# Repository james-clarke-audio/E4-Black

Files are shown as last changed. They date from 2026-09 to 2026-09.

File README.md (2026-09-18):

# E4 — "E4-Black"

An **STM32F411 micromouse**: a C++ port of the ukmars
[**mazerunner-core**](https://github.com/ukmars/mazerunner-core) firmware onto
custom hardware, with a **Web Bluetooth** companion app for live telemetry,
control and calibration. Built for the October 2026 micromouse competition.

> **Status:** active development — hardware bring-up and sensor calibration.

## Features

- **1 kHz control loop** (SysTick) — motion, sensing and the search brain all
  run deterministically.
- **IR wall sensing** — four emitter/detector pairs, ambient-subtracted with a
  batched dark-then-lit read. Two forward sensors (front wall) and two diagonal
  sensors (side walls / centring).
- **Gyro heading** — the gyro holds heading; the side sensors handle lateral
  position and wall presence. Gyro scale is **calibrated on the floor and
  persisted to EEPROM**, not compiled in — it is a property of the individual
  MPU-9250 and shifts with temperature, so it can be re-measured at a venue
  with nothing but the companion app.
- **On-board UI** — SSD1306 OLED with a two-button menu; the whole menu is also
  drivable over Bluetooth.
- **Bluetooth telemetry & control** via the companion app — a Control tab for
  watching and driving her, and a Tuning tab for setting her up: live IR
  monitor, an emitter-hold camera aid for aiming, live turn tuning (gyro-closed
  spins & arcs), and firmware-version reporting.
- **Non-blocking wall sampling** (opt-in) — a five-state sampler ticked from the
  control ISR returns a full ambient-subtracted set every 5 ms with no
  busy-wait, so the wall flags stay live while she's moving.
- **Maze persistence** to on-board EEPROM.
- **Flood-fill search / speed run** from mazerunner-core, with a virtual/real
  sensor switch so the brain can be exercised in simulation.
- **A route executor** — one walk that either drives a planned route or
  rehearses it, so the rehearsal proves the sequencing the driver uses.
- **Time-weighted route planner** — least time rather than fewest cells, with
  diagonals *searched* rather than substituted, and an optimistic twin of each
  plan that says how much is still left to find.
- **Wall follower**, both hands, driven and simulated — its own competition
  class rather than a fallback solver.
- **A simulator that runs at the speed the motion model predicts**, so a
  simulated run takes as long as it claims to and the two numbers can be
  compared. Playback can be sped up for watching; the reported figure never
  moves with it.
- **A maze editor in the companion app** — draw a course on the big canvas,
  save it as text or `.maz`, and send it straight to her. Quicker than hunting
  through 406 files for one that exercises the thing you are testing.

## Hardware

- **MCU:** STM32F411CEU6 (Cortex-M4F, "Black Pill"-class).
- **Wall sensors:** 4× IR pairs — TSAL6100 emitters (940 nm) into OP505A
  phototransistors; emitters switched low-side by FDV301N MOSFETs from a 5 V
  rail. (The original board carried SFH4550; the sensor assemblies now fitted
  are TSAL6100.)
- **Display / storage:** SSD1306 OLED and a 24LC256 EEPROM, both on I2C1.
- **Drive:** DRV8833 motor driver, plus a gyro for heading.

Full pin map, sensor geometry and housing detail are in the reference manual
(see below).

## Build & run

- **Firmware:** STM32CubeIDE (2.2 / GCC 14). Import `Source/` as an existing
  project, build the **Debug** config, and flash over ST-Link to the
  STM32F411CEU6.
- **Companion app:** open `e4-maze.html` in a Web Bluetooth browser — Chrome or
  Edge on desktop, or an iPad via a WebBLE browser such as Bluefy (iOS Safari
  has no Web Bluetooth). Pair over BLE to monitor the sensors, drive the menu,
  and read the running firmware version.
- **Hosted copy:** the repo publishes to GitHub Pages, so the current app is
  always live at
  [`/E4-Black/e4-maze.html`](https://james-clarke-audio.github.io/E4-Black/e4-maze.html)
  and the manual at [`/E4-Black/docs/`](https://james-clarke-audio.github.io/E4-Black/docs/).
  Web Bluetooth needs a secure context, so on a tablet this is the route to use
  rather than copying the file across.

## Documentation

The **E4 Reference Manual** lives in [`docs/`](docs/index.html) — open
`docs/index.html`. Eleven chapters: overview, architecture & pin map, sensor
aim, sensor geometry, sensor housing, the firmware/menu map, position integrity
("Staying Located"), a design note for the next board (STM32G474), how she
chooses her path, the turn table, and the sensor carrier.

## Repository layout

| Path | What it is |
|---|---|
| `Source/` | STM32CubeIDE firmware project (Core / Drivers / Modules / Program). |
| `CompanionApp/` | Native SwiftUI companion (macOS/iPad) + the `E4Core` package — **the tool she is driven from**. |
| `e4-maze.html` | Web Bluetooth companion app (single file); follows the Swift app rather than leading it. |
| `docs/` | The reference manual (`index.html` + chapters). |
| `3D Files/` | Sensor housings, wheels, mounts, and the sensor socket plate (STL, print notes, and the parametric source that generates and verifies it). |
| `tools/planner-bench/` | Native build of the route planner, for scoring routes against the maze files without a robot. |
| `tools/bench-mazes/` | Finds and writes the per-turn tuning rigs, and checks the shipped files by planning them. |
| `mazefiles/` | 408 real competition mazes, binary and text, plus `bench/` — twelve single-corridor tuning rigs. |
| `E4-cell-alignment-A4.pdf` | 1:1 print jig for squaring a test cell. |

See [CONTRIBUTING.md](CONTRIBUTING.md) for the fuller layout and workflow.

## Contributing

`main` is protected: collaborators work on a branch and open a pull request.
Details, commit style and the firmware-version convention are in
[CONTRIBUTING.md](CONTRIBUTING.md).

## Credits

Firmware is a port of Peter Harrison's ukmars **mazerunner-core**. Thanks to the
UK micromouse community.

## License

Released under the [MIT License](LICENSE) — © 2022 Peter Harrison
(ukmars mazerunner-core), © 2026 James Clarke. E4 is a derivative of the
MIT-licensed mazerunner-core and keeps the same terms.

---

## Firmware releases

`FW_VERSION` lives in `Source/Program/inc/version.h`, shows on the OLED splash
and is reported over Bluetooth (`VER?`). **Minor** for a feature, **patch** for
a fix. **1.0.0 is reserved** for the build that goes to the October competition
— everything before it is bring-up.

Each entry names the firmware commit; companion-app and docs commits that
landed alongside are listed after it, since the two move together. Newest
first.

**0.34 — 18 Sep 2026 · The post loop**
From an old lab note of James's: drive into a cell, then round a post
continuously, watch the centre drift and adjust α. It is a better rig than the
zigzag, and one line of geometry says why.

**Four chained same-hand 90s of radius 90 *are* a circle centred on a post.**
She comes up the lane at x = 90 turning right; the arc centre sits 90 mm to her
right, which is the post. After the quarter she is heading east and her right is
now south — the same point. Every quarter shares a centre, so the four are one
circle, 565.5 mm round.

Which pins ω: `R = v/ω`, so R = 90 at 300 mm/s needs **191 °/s** — the figure
`SS180` already holds, because its lateral step of 2R is also one cell. And it
reconciles the two numbers in Ch 10: **226 is the figure for a turn driven on
its own**, where ω ramps to zero at the end and the trapezoid swings wider than
the ideal circle. Driven continuously there are no ramps between the quarters,
so the ideal `R = v/ω` applies and 191 is simply right. Two manoeuvres, two
answers, and the loop is the one that matches what a chained turn has to be.

**It separates ω from α.** Over a closed lap the four local frames sit at 0°,
90°, 180° and 270°, so any consistent per-turn displacement error sums to zero —
radius, offsets, tangential lag alike. Heading does not: the frames precess, the
lap stops closing, and the centre walks by about `2.83·|d|·ε`.

| error per turn | drift per lap | after 8 laps |
|---|---|---|
| 0.1° | 0.6 mm | 5 mm |
| 1.0° | 6.3 mm | 50 mm |

So ω sets the *size* of the circle and α sets the *drift* of its centre. It is
also the honest gyro-scale test — at running speed with the wheels rolling
rather than scrubbing in place — and the two causes separate, since scale error
is speed-independent while α's grows with ω. Odometry gives the radius back for
nothing: arc distance over 2π·laps, reported as `R_meas` beside the 90 it wants.

`Post loop` (Calibration, or BT `A`), set up by `LOOP,laps,ω,α,hand,speed`. It
is its own menu action rather than another use of `ARC` because **1440° is not a
turn** and writing it into a row would ruin the row.

*Alongside:* page 15 of `E4-bench-diagnostics-A4.pdf` draws the rig — a 2×2
block with the middle post free-standing, the 90 mm circle to mark round it, the
tangent run-in, and what a degree per turn looks like after one, four and eight
laps. Her outline on every page is now the real one: the chassis board is 77
wide with wheel wells stepping in to 11.46/65.54, 100 long with a semicircular
nose of radius 38, and the axle 35 mm from the back — all of it already written
down in Ch 11, Ch 4 and `config.c`.

**0.33 — 18 Sep 2026 · The approach is part of the turn**
A tuning run is *drive to the turn, make it, drive out* — and the first of those
three was the one the tuner could not be asked for. `ARC`'s fifth field writes
`entry_offset`, and `run_arc_from_table()` passed `entry_offset` straight in as
the lead-in, so the arc always began that many millimetres after she started
moving. Fine for "does this arc look right"; useless for "does she come out of
it in the lane", which is the only question a bench answers.

The approach is now counted in cells and the millimetres derived:

| entered from | lead-in |
|---|---|
| a straight | `BACK_WALL_TO_CENTER + cells × FULL_CELL − entry_offset` |
| the diagonal | `cells × DIAG_PITCH − entry_offset` |

`DS45`, `DS135` and `DD90` begin **on** the diagonal, where the pitch is 127.279
and there is no back wall to square up on — she is placed on the line by hand.
Which case applies follows from the row rather than from a switch someone has to
remember: a turn that leaves the diagonal is a turn that was already on it.
`POS,<cells>` sets it, `TUNE,pos=,lead=,pitch=` reports what she will actually
drive *before* anything moves, and `TURNRES` carries the row and the lead so a
log line three runs back still means something.

**The card does the arithmetic before she does.** `R = v / ω`, and an arc joining
two lanes that cross at θ is tangent to both only at `R·tan(θ/2)` either side of
the crossing. There is one wrinkle, and it took drawing the maze out 1:1 to see
it: `entry_offset` is measured back from the **lattice point** the planner books
the turn at, which for most turns is also where the two lanes cross — but an
`SD45` is booked in at a **cell centre**, while a straight lane meets a diagonal
at the **wall midpoint 90 mm earlier**. That half cell is part of the offset.

| row | ω | R at 300 | tangent | + half cell | needs | has | |
|---|---|---|---|---|---|---|---|
| SS90E | 170 | 101 | 101 | — | 101 | 100 | agrees |
| DD90 | 273 | 63 | 63 | — | 63 | 63 | agrees |
| **DS45** | **95** | **181** | **75** | **—** | **75** | **120** | **does not** |
| **SD45** | **95** | **181** | **75** | **90** | **165** | **120** | **does not** |

So the two 45 rows cannot both be right while they share a number — one needs
165 and the other 75. The same 120 sits in the planner as `sd45_offset` /
`ds45_offset`, so those move with them. The Tuning screen shows the gap and
offers the figure; the floor decides which of the numbers was wrong, but it
cannot until they agree.

One number says it best: a diagonal step is 127.3 mm and `ds45_offset` is 120 of
it, so on `bench-3x3-45min` the DS45 gets **seven millimetres** of approach
before the arc starts. At the tangent value it gets 52. That is why the planner
abandons that geometry and drives `ARC_R, SPIN_L` instead.

*Alongside:* `E4-bench-diagnostics-A4.pdf` — the 1:1 cell template (centrelines,
corner-to-corner, and the diamond joining the four wall midpoints that is the
actual diagonal lane), plus a page per hand showing where the mouse gets put
down. `06fc12d` and `fa6d585` — `mazefiles/bench/`, twelve single-corridor
tuning rigs, and `tools/bench-mazes/` which found them by enumerating every
corridor that fits in a section and asking the real planner what each one
produces. Two results fell out of that search. A 3×3 entered at (0,0) facing
north can only turn right first, because the west perimeter is beside her —
`SD45_L` is unreachable there without a spin. And **(2,0) facing north is the
mirror image of (0,0) facing north**, so once the start pose is allowed to move,
every left-hand rig is the x-mirror of its right-hand twin, walk for walk.

**0.32 — 18 Sep 2026 · She can finish by turning into the goal**
Every goal test in `plan_native()` sat inside the cell-expansion loop, which
advances a cell *before* it looks. So a route that **arrives** at the goal by
turning into it was never recognised as finished: she drove past and came back,
or took a longer way round that happened to approach along a straight.

The node's own cell is now tested before the loop, with `best_cells = 0` and
`best_t = 0` because the turn that brought her there is already paid for in
`key`. `step_time()` returns `0.0f` for a zero-cell goal step rather than asking
`straight_time()` for a negative distance — the clock stops on *entering* the
goal, and what is left of that cell afterwards is not on it.

On Boston the last vertices went from `DS45_L (17,18) → (17,17) → GOAL (17,15)`
to `… → GOAL (17,17)`. Swept over the whole 394-maze corpus: **72 faster, 320
unchanged, 2 slower, 0 invalid**, mean 32.864 → 32.761 s. Best: japan1997f
−3.460 s, uk1992q −2.698 s, boston −1.544 s.

The two slower ones are not a regression in the fix. `key_of()` quantises time
to centiseconds — that is what makes Dial's bucket queue O(E) — so routes tying
on the quantised key can differ by up to ~10 ms a step, and ≤0.13 s over twenty
steps is inside one bucket width. Recorded here so nobody hunts it later.

**0.31 — 18 Sep 2026 · No toy maze at boot, and the editor can undo**
The boot scaffold seeded a two-cell maze with the goal at (1,1). It made a whole
class of mistake invisible: a Plan route run with **no maze sent** looked
entirely successful, because there really was a maze and she really did solve
it. She now boots with `maze.h`'s own `m_goal{7, 7}` and an open arena as ground
truth, so a run with nothing sent looks like what it is.

The companion app's maze editor grows undo — `history: [E4MazeFile]` with
`canUndo` / `undo()`, and ⌘Z on the canvas.

**0.30 — 17 Sep 2026 · She speeds up through ground she has already covered**
Watching a simulated explore, she never went any faster in cells she had already
been through — and she didn't, in either the simulator or the firmware.
`sim_move_seconds()` used `FULL_CELL / SEARCH_SPEED` for every cell, and
`search_to()` crawls at `SEARCH_SPEED` from the first cell to the last. The
simulator was faithfully showing what the firmware does, which is the simulator
doing its job.

**The test is per cell, not per leg.** The obvious version of this is to run the
whole return leg fast, on the grounds that she has just driven it. That is
wrong: the flood picks the best *known* path home and known does not mean
*visited* — she will have seen a cell's walls from next door without ever
entering it, and those cells are exactly where there is still something to
learn. So the return leg becomes an exploring run that happens to be quick in
the parts already covered.

`cruise_speed()` is that rule, in one place, used by the driven search and the
simulated one so neither models something the other does not do:

| condition | speed |
|---|---|
| the cell she is **entering** is fully visited, **and** the move out of it is straight | `RUN_SPEED` |
| anything else | `SEARCH_SPEED` |

The second condition is the one that is easy to forget. There is no room to shed
speed between a cell's sensing point and the turn point after it, so carrying run
speed into a turn means entering it too fast. Checking costs nothing: in visited
territory the map is complete, so `heading_to_smallest()` on the flood she
already has is a reliable one-cell look ahead.

**And a sloppy read at speed cannot hurt her**, which is what makes this safe
rather than merely fast. She still senses and still calls `update_map()` in a
cell crossed at 600 mm/s — but `update_wall_state()` refuses to change a wall
that has already been seen, and *fully visited* means every wall in that cell
has been. A bad reading is discarded by construction, in exactly the cells where
the rule allows speed. The only place a wrong wall could be written is a cell
with something unknown in it, and those are the cells she is required to crawl
through.

`sim_move_seconds()` now tracks the speed she is **carrying** and costs each move
with `timing::straight_time` — the planner's own model — so a run of visited
cells visibly winds up and the cell before a turn visibly sheds it, instead of
every cell costing a flat 0.6 s.

The wall follower stays at search speed throughout, deliberately: `cruise_speed()`
reads the flood to look ahead, and a follower never floods.

**0.29 — 17 Sep 2026 · The executor left a diagonal by the wrong side**
A diagonal speed run finished at **(1,0)** — near the start, nowhere near the
goal — having walked a staircase west and south with no 45° heading in it, on a
route whose time came back exactly right at 23199 ms.

One line. `run_route` left a diagonal with `nh = (L) ? ((dd + 3) & 3) : ((dd + 1) & 3)`.
"+3 to turn left" is correct *inside* an enum. This crosses from `Diag` to
`Head`, and those are different enums offset by half a turn: leaving a diagonal
to the left is **+0** and to the right is +1. The right hand was accidentally
correct, which is why it took a real route to expose.

What it does is worse than a wrong heading: it lands her on a **post**, the one
lattice point that is never occupied, so her half-cell coordinates lose their
parity and every orthogonal move afterwards keeps her on the wrong parity for
the rest of the route. Hence a whole run animated on the lines *between* cells —
which is exactly what the `POS` trail showed, every coordinate an even multiple
of 90.

Fixed in **one place, not two**: `diag_ccw`/`diag_cw` move from statics in
`native.cpp` to inline functions in `native.h`, so the executor uses the same
mapping `route_points()` does rather than a second copy of it. Two copies of that
mapping is how one of them went wrong.

And the walk checks itself now. A route ends at a cell **centre**, odd in both
half-cell coordinates; anything else means the walk lost the lattice and every
cell it has reported since is fiction. It says so — `SR,LOST u= v= diag=` —
rather than reporting a plausible wrong answer.

Verified on the maze that broke it: every vertex of the run now matches the
planned route exactly, and she finishes at (8,8).

**0.28 — 17 Sep 2026 · The route executor**
The planner has been able to answer since 0.20 and nothing acted on the answer.
`run_route()` does.

**One walk serves both the real run and the rehearsal.** The part worth getting
right is the sequencing — which turn, after how many cells, from which heading —
and a simulator that sequenced differently from the driver would prove nothing
about the driver. The only thing the `simulate` flag changes is whether a step
is animated or driven.

Timing comes from a new `route_times()` in `diagonal.cpp`, which walks the route
with the **same `step_time()` that costed it** and reports each step split into
the run before the turn and the turn itself. That split is what lets the
rehearsal animate a step at its true duration, and it means the simulated total
equals `route.seconds` by construction rather than by coincidence.

    Sim speed run   F    plan, then rehearse at the speed the model predicts
    Speed run       l    plan, then drive
    KIND,<0|1|2>         shortest · quickest · quickest with diagonals

Which route is a **setting** rather than three menu entries, because the three
are one run with a different cost function and the point is comparing them back
to back on one maze. The default is quickest orthogonal: the diagonal route is
faster on paper, but every diagonal row of the turn table is arithmetic that has
never met a floor.

Both actions **stream the route before executing it**, so the line she is about
to take is on screen before she takes it, and a run that goes wrong can be
compared against what she meant to do rather than against memory.

One simplification, named in the code rather than hidden: in the simulated turn,
position advances during the run and heading rotates at the vertex, so an arc
looks like a spin on screen. The *time* is right either way and the route line
shows the true path — but the animation is not evidence about arc geometry.
**Zigzag test** is what answers that.

> `act_speed_run` is **unproven**. No part of the driven path has been near a
> floor, and the turn table it reads is arithmetic outside the two SS90E rows.
> It arms and waits like everything else; give her room.

**0.27 — 17 Sep 2026 · The followers arm like everything else, and say so**
Two bugs, both from 0.25. `follow_to()` **did not wait** — every other action
that turns a wheel calls `sensors.wait_for_user_start()` before it moves, and
the driven wall follower went straight from a tap in the app to driving. It arms
now, and so does the simulated twin, so both halves of the pair behave the same
way and neither teaches a habit the other punishes.

The four followers were also missing from `waitsForButtonPress`, which is why
pressing one in the app looked like nothing happening: she printed
`armed: press a button to launch` and blocked, correctly, and the app had no way
to tell a deliberate pause from a dropped command. Both apps now put that
message in front of you rather than leaving it as one line among hundreds, and
the **Actions** screen gets the same armed banner the maze screen already had —
it had been showing `Running:` for an action doing nothing of the sort.

**0.26 — 17 Sep 2026 · The simulator runs at the speed the model predicts**
`sim_step` animated eight frames of thirty milliseconds whatever the move, so a
cell crossing, a 90 and a dead-end reversal all took 240 ms and the simulator
told you nothing about time. It takes a **duration** now and the frames follow
from it, and that duration comes from `timing.h` — the planner's own model, not
a second one written for the animation, so the two cannot drift into different
opinions about the same mouse.

| move | cost |
|---|---|
| `AHEAD` | one cell at search speed |
| 90 | an **arc**: she rotates *while* she travels, so it is whichever of the two takes longer, not the sum |
| `BACK` | the one move that does not overlap — `turn_back()` stops dead, spins on the spot and moves off again, so that one adds up |

Getting the 90 wrong the other way is how a simulator flatters a route full of
corners; getting `BACK` wrong is how it flatters one full of dead ends.

The reported time is now the **modelled** clock, not `HAL_GetTick()`. The two
agree to within the odd frame, which is exactly why the wall clock must not be
the one reported — a slow link or a stalled frame would read as a slower mouse,
and the figure would stop being a property of the route. Real search runs are
untouched; there the wall clock *is* the truth.

Two details decide whether it is honest. The frame deadline **absorbs** transmit
time rather than adding to it (a `POS` and `TEL` pair is about 56 bytes, roughly
10 ms of wire at 57600, so delaying a full frame on top would run every run a
third slow). And `SIM_RATE` — `SIM,<rate>` over BT, a picker in both apps —
scales the *watching* only, because a real-time explore is forty-odd seconds and
nobody should sit through that twice, but the number she reports must not move
when you skip ahead.

**0.25 — 17 Sep 2026 · The wall follower, both hands, driven and simulated**
`follow_to()` had been sitting in `mouse.h` implementing a left-hand follower the
whole time, with `act_wall_follow` still an `act_todo` stub, so nothing could
reach it. It takes a hand now:

    20  Wall follow L   w        32  Wall follow R   W
    33  Sim follow L    q        34  Sim follow R    Q

Four entries rather than one action with a hand setting, because the hand *is*
the experiment — left and right walk different halves of a course. The
simulated pair animate the same decision with the motors never armed, so both
hands can be run against any maze file with no bench at all.

**A wall follower is its own competition class, not a weaker solver.** A
follower course is built with a wall connected all the way to the centre, so a
follower always arrives — that is the point of the event. A maze-solver maze is
built the other way round, with the inside deliberately disconnected from the
outside, so a follower can never reach the middle of one however long it walks.
Same code, two events.

So `FOLLOW_STEP_LIMIT` (512, four times the cells in the arena) is not a guard
against a weak algorithm — on its own course it never trips. It exists because
this code gets pointed at a solver maze in the simulator, where **not arriving
is the correct answer**, and the only wrong behaviour would be walking for ever
while that is true. Giving up reports `WF,gave up after N cells (left hand)`.

Of the **406** files in `mazefiles/binary`, **90 are follower-solvable and 316
are not** — and it is the *same* 90 for both hands, with not one maze yielding
to one hand and not the other. That is structural rather than luck: the hand
decides which route she walks, not whether the centre is reachable. If the
centre's walls are connected to the perimeter, both hands are walking the same
wall component; if it is an island, neither can. Five of the 90 are built for
the class explicitly — `uk2010follower`, `uk2011follower-final`,
`tic05followersheats`, `robotic-2011-follower-heats`, `-finals` — and 33 are
competition mazes including `japan1991`, `uk2003q` and `uk2009f`. `test3.maz`
arrives in 14 cells if you only want a smoke test.

**0.23 — 16 Sep 2026 · How much of the route is still guesswork**
"Have I explored enough?" had no answer but a feeling. It has one now, and it is
a proof rather than a percentage.

`act_plan_route` already flips the wall mask, so the second plan is nearly free.
`MASK_CLOSED` treats an unseen wall as a wall and yields the best route she can
**prove**. `MASK_OPEN` treats it as an opening and yields the best route that
could **possibly** exist — a true lower bound, because the real maze has at
least as many walls as the optimistic view of it. The gap between them is the
most that is still out there to find, and when it closes her route is not
probably the best, it **is** the best and no further exploring can change it.

The cells worth driving to are exactly the not-yet-fully-seen cells *on* the
optimistic route. That is the sharp version of "explore what is left": an
unknown cell no optimistic route passes through cannot change the answer,
however blank it looks on the screen. A long corridor whose north walls she
learned from driving the row above, and whose east–west state she knows nothing
of, only matters if the best possible line wants to go down it.

    RB,<kind>,<ms>,<unknown cells on that route>
    RU,<x>,<y>  …  RUE,<total>        the union — and only these matter

The union is taken across all three kinds deliberately: it is a superset of what
an orthogonal-only run needs, which is the safe direction to be wrong in while
the diagonal arcs are untuned.

`route_cells()` in `native.cpp` walks a route and emits every **cell** it
covers, which is a different set from `route_points()`' corners — a six-cell
straight is two points and six cells, and a diagonal step is no point at all but
does cross one cell. The OLED shows known, best possible and the unseen count,
and reads `PROVED` when there is nothing left; both apps draw the unseen cells
as dashed amber squares under the route lines.

**0.22 — 16 Sep 2026 · Fast-run speeds, separate from the search speeds**
`act_plan_route` built its `Robot` from `SEARCH_SPEED` and `SEARCH_ACCELERATION`,
so it was planning the **fast run at search speed**. That is why `SHORTEST` and
`QUICKEST` came back at 27.245 s each with identical point lists on the bench
mouse: told that a straight is no quicker than a corner, the planner has nothing
to choose between.

Search speed is bounded by sensing — she reads walls and decides where to go
once per cell — and is settled at the bench. The fast run has no such limit,
because the map is already known.

    RUN_SPEED         600 mm/s     twice the search speed, a timid opening bid
    RUN_ACCELERATION  2000 mm/s²   as the search, until it is measured
    RUN_DIAG_SPEED    300 mm/s     the diagonal corridor is 110.3 mm between
                                   posts against 168 down a cell — about 14 mm
                                   a side with the plate on. She threads it.

The **arc** speeds are untouched and stay as the turn table holds them. They are
independent: she can run a six-cell straight flat out and still take every SS90
at the speed its row was tuned at, and that independence is the whole mechanism
by which a longer, straighter line starts to beat a shorter, twistier one.

Runtime rather than `const`, like the turn table and the spin dynamics — `SPD?`
and `SPD,v,a,diag` over BT, persisted as config block **v6**. Nothing drives on
them yet (`act_speed_run` is still a stub), so a wrong value costs an estimate,
not a mouse.

Sweeping the straight speed across the full competition mazes says where her lap
time actually lives:

| `v_max` | 300 | 600 | 1000 | 1500 |
|---|---|---|---|---|
| tricky.maz | 67.83 s | 51.93 s | 47.87 s | 46.80 s |
| APEC2017.maz | 71.97 s | 52.39 s | 46.93 s | 45.02 s |

300 → 600 buys 23%. 600 → 1500 — two and a half times the straight speed — buys
another 10%. The routes are **turn-dominated**: sixteen arcs at 300 mm/s swamp
what the straights can save, so the turn table is worth more bench time than the
straight-line number.

Two fixes landed with it. `act_plan_route` was planning to a **1×1 goal** when
the goal is a 2×2 room, so she drove *through* two goal cells to reach the one
square she had been told to reach — work done after the clock had already
stopped. And the app was never sent the **perimeter**: `maze.initialise()` walls
the outside of the arena before a single sensor reading, but `W` lines are only
sent for cells she stands in, so the border was known at both ends of the link
and sent over neither.

**0.21 — 16 Sep 2026 · The planner reaches the app**
`Plan route` (Maze solver, or `P`) runs the planner three ways over the map she
is currently holding — shortest, quickest, quickest-with-diagonals — and streams
each to the companion apps, which draw all three over the same maze. No motors,
so it works on an injected maze, a remembered one, or one she has just explored:
a whole run can be rehearsed at the bench before she drives a cell of it.

Points go out in **half-cells**, which is the unit the planner's lattice already
works in. Cell centres land on odd coordinates and wall midpoints on mixed ones,
so a diagonal arrives at the app as an ordinary pair of points — neither
companion has to know about the lattice, the parity rule, or which wall a point
sits on. Draw a polyline through them and it is right.

    RT,<kind>,<ms>                      kind 0 shortest, 1 quickest, 2 diagonal
    RP,<u>,<v>,<move>                   a vertex in half-cells
    RTE,<points>,<cells>,<turns>,<spins>

The firmware carries only `native.cpp`: with diagonals disabled it *is* the
orthogonal planner, and `tools/planner-bench/xcheck` confirms the two agree in
shape on all 392 mazes. That keeps `planner.cpp`'s 36 KB out of the build.

Both apps also gain **Zigzag test** and the `ZIG,turns,mode,first` setup, so the
chained-arc question can be settled without the OLED.

Documented in [Ch 12 — Planning the Fast Run](docs/e4-planner.html); the
[Build Map](docs/e4-build-map.html) now shows the diagonal capstone as half
done — the planner is shipped, the 45° *motion* is what is left.

**0.20 — 16 Sep 2026 · Diagonals, searched rather than substituted**
`native.cpp` puts the diagonal moves into the graph and searches, instead of
planning orthogonally and rewriting afterwards. Work in half-cells and parity
says what a point is — (odd,odd) a cell centre, mixed a wall midpoint,
(even,even) a post — and a diagonal is a straight line through wall midpoints
stepping ±1,±1, so it never lands on a post. It is *not* the line joining cell
centres diagonally: that goes straight through one. Because it searches, it can
take a **longer** cell route because that route diagonalises better, which is
the one thing post-processing can never do.

Across 392 real competition mazes, against the orthogonal quickest route:
classic substitution **−3.4%**, native search **−13.2%**, best −47.6% on
`quo4`.

`route_check()` walks a route over the lattice against the map, independently
of whichever planner produced it — because the two disagreed and a planner that
scores its own output is only as honest as its own model. It found that classic
was reporting times for routes she could not drive: the exit hand off a
diagonal is fixed by the lattice rather than by the zigzag, and the diagonal
does not end in the cell the zigzag ended in. Fixing both took classic from a
claimed 8–10% to a real 3.4%. Both methods now pass on all 392.

Documented in [Ch 12 — Planning the Fast Run](docs/e4-planner.html). Still
nothing calls any of it, so there is still no speed run.

**0.19 — 16 Sep 2026 · A route planner, and a test to prove it wrong**
Two new modules that nothing drives yet, and one bench routine that exists to
settle an argument between them and the firmware.

`planner.cpp` answers *least time* where the flood in `maze.h` answers *fewest
cells* — a different graph, not a replacement. Time is not additive per cell
(she accelerates, so four one-cell moves and one four-cell straight differ), so
nodes are turns rather than cells and an edge is "run N cells, then turn". The
FIFO had to go with it: a plain queue is correct only while every edge costs
the same, which is what unit cost bought. It is Dial's algorithm now — a
circular bucket queue, still O(E), with a guard that invalidates the plan
rather than clamping if an edge outgrows the ring.

`diagonal.cpp` does classic diagonal substitution on the result, costing every
candidate both ways and substituting only when the diagonal actually wins.
**Worth 3.4%** across 392 real competition mazes. An earlier version of this
entry claimed 8–10%; that figure came from routes she could not have driven,
and is corrected in 0.20.

**Zigzag test** (Calibration, or `Z`) drives N alternating 90s in consecutive
cells with no straight between, ending stopped at a cell centre so the offset
can be measured. It is there because the planner and `turn_smooth()` disagree:
at R = v/ω ≈ 101 mm two arcs one cell apart need 202 mm and have 180, so the
planner refuses and emits stop-and-spin — while `turn_smooth()` relabels the
frame past the next turn point and simply runs the arcs back to back. `ZIG,` over
BT sets turns, mode (chained arcs or spins) and first direction. Whichever way
it comes out, one of the two is wrong and the 8–10% diagonal figure moves with it.

Neither planner module is called by anything; `--gc-sections` drops all 36 KB
of the planner's working set until something does.

**0.18 — 13 Sep 2026 · Connecting greets her, not drives her**
The app asked for the firmware version by *running the menu action*, which
parks on the OLED waiting for a button press — on a screen nearly identical to
the boot splash, so she read as hung, and the menu cursor was left sitting in
Diagnostics. Replaced with a `VER?` query that answers without touching the
menu.
`f9c32fd` · tests `9a5f6d8`

**0.17 — 13 Sep 2026 · The whole configuration, on demand**
`CFG?` dumps every persisted value — gyro scale, the three wall thresholds, all
sixteen turn rows and the spin dynamics — so the app can show what she is
actually running rather than what it last sent her.
`246aeec`

**0.16 — 13 Sep 2026 · Spins join the table**
`OMEGA_SPIN_TURN` / `ALPHA_SPIN_TURN` become runtime values: tunable over
Bluetooth (`SPIN,…`) and saved with everything else. Config block goes to v5.
`9c71672`

**0.15 — 13 Sep 2026 · Slots for the diagonal set**
The turn table grows from four rows to the full sixteen — SS90E, SS90, SS180,
and the diagonal entries and exits (SD45, DS45, SD135, DS135, DD90), left and
right. The diagonal rows carry computed geometry and sit inert until the
diagonal solver exists.
`6bc5987` · docs `d1c8ef4` (Ch10, the turn table)

**0.14 — 13 Sep 2026 · One turn, tunable live, saved to EEPROM**
There were three separate copies of the same 90° turn and they had already
drifted apart — the menu ran alpha 1000 where the search brain ran 2500.
Collapsed into a single `turn_params[]` table that the menu, the search brain
and the tuner all read from, editable over Bluetooth and persisted.
`4f0f4d1`

**0.13 — 13 Sep 2026 · Show what is running, on both displays**
Commands sent from the app bypassed the menu, so the OLED carried on showing
something else entirely. The menu cursor now follows whatever action actually
runs, wherever it was started from.
`d339d11` · app `f2d5cd0`, `11cd734`, `b323651`, `b828179`, `108e0c8`, `382c723`
(threshold calibration drawn rather than described; session replay)

**0.12 — 13 Sep 2026 · Threshold calibration: the third capture**
Two captures — walls present, walls absent — cannot describe a corridor, where
the sides see wall and the front does not, which is the state she spends most
of her life in. Added a third capture and generalised the margin test to
weakest-present against strongest-absent.
`93a3c9c` · app `ee8095a`, `02bf440`, `167dc30` (maze file import and upload)

**0.11 — 12 Sep 2026 · Per-sensor wall thresholds, calibrated and persisted**
One shared side threshold became `WALL_THRESH_LEFT` / `_RIGHT` / `_FRONT`,
settable over Bluetooth (`THR,l,r,f`), captured by a guided routine and saved
to EEPROM. Also fixed the EEPROM self-test, which had been writing its scratch
pattern to address 0 — over the maze store.
`12142da` · app `3dbdb43` · docs `7b189fa` (Ch9, how she chooses her path)

**0.10 — 11 Sep 2026 · One-press Bluetooth bring-up**
A replacement module can be provisioned from the menu — name set to `MMOUSE`,
baud to 57600 — with no serial adapter and no guesswork.
`8c0b13a` · app `64b5e6f`, `2ce5fc9`, `2a243a9`, `29ccaab` (the native SwiftUI
client starts here: sidebar, seven screens, session logging)

**0.9 — 11 Sep 2026 · Gyro scale becomes a runtime value**
`GYRO_SCALE` moves out of the source and into the config store: spin a known
angle, send the error, save. It is a property of the individual MPU-9250 and
shifts with temperature, so it has to be re-measurable at a venue with nothing
but the app.
`f03e0b8`

**0.8 — 10 Sep 2026 · Non-blocking IR sampler**
A five-state sampler ticked from the control ISR returns a full
ambient-subtracted set every 5 ms with no busy-wait, so the wall flags stay
live while she is moving.
`1498a93` · app `daa2db3`, `2e7a50a` · repo `2fcd708` (CODEOWNERS), `1c77a9d`

**0.7 — 9 Sep 2026 · Live turn tuning over Bluetooth**
`act_turn_tune` stops being a stub: parametric in-place spins and arcs run on
command and stream back the achieved gyro angle and forward distance, so turn
dynamics can be tuned against the surface she is actually on without
reflashing.
`3ae1b6e` · app `910cb1b` · docs `e2a6766` (Ch7), `381987e` (Ch8)

**0.6 — 8 Sep 2026 · Batched IR read, ADC timing, menu tools**
Two-phase batched wall read (dark, then per-emitter lit) and IR sample time
raised from 3 to 28 cycles. First release with a stamped version.
`63e09fa` · app `2f60ad7` · docs `c0be1df` (the manual moves into the repo)

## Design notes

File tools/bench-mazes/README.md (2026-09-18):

# Bench mazes: one rig per turn

Every turn she drives has to be profiled on the real floor, and profiling a
turn buried in the middle of a competition maze tells you very little -- by the
time she reaches it she is already carrying whatever error the turns before it
left behind. So each turn gets its own maze, small enough to build out of the
physical sections on the bench.

A section is 3 cells by 3 cells. Two of them butted together give 6x3. Each
maze here is a **single corridor**: no junctions anywhere, so there is exactly
one route through it and the planner cannot quietly decide to test something
else while you are watching the floor.

The generated files live in `mazefiles/bench/`, as both `.txt` (ASCII, carries
the goal cell) and `.maz` (binary, no goal). **Load the `.txt`** -- the goal is
the whole point and the binary form cannot express it.

## The start pose is part of the rig

On the bench she is placed by hand, so she does not have to begin in the
competition corner. That turns out to matter more than it sounds, because of
one piece of geometry:

> **(2,0) facing north is the mirror image of (0,0) facing north** -- and
> mirroring is exactly what swaps left for right.

Which is why the tables below come in pairs. Every left-hand rig is the
x-mirror of its right-hand twin, walk for walk, and the two plan to identical
times with every turn's hand flipped. `bench-3x3-90R` from (0,0) gives three
`ARC_R`; `bench-3x3-90L` from (2,0) gives three `ARC_L`. Same corridor shape,
same section, other hand.

From the competition corner alone none of that is available: facing north at
(0,0) with the west perimeter beside her, her first turn in a 3x3 can only be a
right, and `SD45_L` is not reachable at all without a spin in the route.

Her heading at the start is the first letter of the walk. The start cell always
has exactly one opening, so wherever she is put down her back is against a wall
to square up on. The ASCII files mark it `S`.

## The rigs

One section each -- four pairs, one pair per turn family:

| file | start | corridor | goal | route |
|---|---|---|---|---|
| `bench-3x3-90R` | (0,0) N | `NNEESSW` | (1,0) | `ARC_R` x3, nothing else |
| `bench-3x3-90L` | (2,0) N | `NNWWSSE` | (1,0) | `ARC_L` x3, nothing else |
| `bench-3x3-45minR` | (0,0) N | `NEN` | (1,2) | `SD45_R DS45_L`, ONE diagonal step |
| `bench-3x3-45minL` | (2,0) N | `NWN` | (1,2) | `SD45_L DS45_R`, ONE diagonal step |
| `bench-3x3-45R` | (0,0) N | `NENE` | (2,2) | `SD45_R DS45_R`, two steps |
| `bench-3x3-45L` | (2,0) N | `NWNW` | (0,2) | `SD45_L DS45_L`, two steps |
| `bench-3x3-dd90L`  | (0,0) N | `NENW` | (0,2) | `SD45_R DD90_L DS45_L` |
| `bench-3x3-dd90R`  | (2,0) N | `NWNE` | (2,2) | `SD45_L DD90_R DS45_R` |

Two sections each, for the runs that need room:

| file | start | corridor | goal | route |
|---|---|---|---|---|
| `bench-6x3-90R` | (0,0) N | `NNEEEEESSWWWWN` | (1,1) | four `ARC_R`, no other turn kind |
| `bench-6x3-90LR` | (0,0) N | `NNEESSEEENNWWS` | (3,1) | `ARC_R` x2 then `ARC_L` x4 |
| `bench-6x3-diag-R` | (0,0) N | `NENEEESESWWNWSW`  | (1,0) | `SD45_R` x3, `DS45_R` x4, both `DD90`s |
| `bench-6x3-diag-L` | (0,0) N | `NESEEENENWWSWNWW` | (0,2) | `SD45_L` x2, `DS45_L` x4, both `DD90`s |

## Using one to tune a turn

These are layouts, not problems to solve — nothing here needs the planner. Set
the section up, put her down where the sheet says, and drive **one turn**:

1. **Enter tuner** (firmware action 19).
2. `SEL,<row>` — or pick the row from the list on the Tuning screen, which
   names them from her own table so it cannot drift.
3. `POS,<cells>` — the approach. The lead-in is derived, `49 + 180 x cells -
   entry_offset` from a back wall or `cells x 127.279 - entry_offset` for a turn
   that begins on the diagonal, so it follows `entry_offset` instead of being
   re-typed after every change to it.
4. `ARC,...` — she drives the approach at constant speed, makes the turn, and
   runs out along `lead out`, streaming pose at 20 Hz the whole way.
5. Read the lane she finished in. `S` saves to EEPROM when you believe it.

**`E4-bench-diagnostics-A4.pdf` has a page per row**, drawn from that row's own
numbers: where she is put down, where the two lanes cross, the arc she should
make, the arc the table makes today, and the gap between them in millimetres.
Page 1 is the only 1:1 sheet; the rest are pictures.

**One turn at a time.** Chaining an SD45 into a DS45 and reading the finish
measures their sum, because a lateral error out of the first moves the start of
the second. Do them separately: run the SD45 and judge her against the diagonal,
then place her on the diagonal by hand and run the DS45.

**Trim the offset, not omega.** Both move her laterally — at 45 degrees, 1 mm of
entry offset is 0.71 mm and 1 deg/s of omega is 0.56 mm, so they have comparable
authority. But omega sets the radius and the radius has to fit the space it is
turning in; the offset is free. Fixing a placement error by changing the
geometry leaves a radius that no longer suits the corner.

## And one rig that is not a corridor

The **post loop** needs a 2x2 block with the middle post free-standing -- four
cells, no walls between them -- and a 90 mm circle drawn round that post. It is
not in `mazefiles/bench/` because nothing plans it: `Post loop` (Calibration, or
BT `A`) drives it directly.

Four chained same-hand 90s of radius 90 ARE that circle. She comes up the lane
at x = 90 turning right; the arc centre sits 90 mm to her right, which is the
post, and it is the same point every quarter. So the four turns are one circle,
565.5 mm round, and because she drives it continuously there are no ramps
between them -- the ideal `R = v/omega` applies and omega is pinned at
**191 deg/s** at 300 mm/s.

Over a closed lap every consistent displacement error cancels, because the four
local frames sit at 0, 90, 180 and 270 degrees. Heading does not cancel, so the
centre walking away from the post is a direct read of alpha and the gyro scale:
about 6 mm a lap per degree per turn, which turns a tenth of a degree into five
millimetres over eight laps. **Omega sets the size of the circle; alpha sets the
drift of its centre.**

`LOOP,8,191,2500,1,300` sets it up. `R_meas` in the result is the achieved
radius straight out of odometry -- arc distance over 2*pi*laps -- so the size
half of it needs no ruler at all. Page 15 of `E4-bench-diagnostics-A4.pdf` draws
the rig and what the drift looks like.

## The 45 rigs are the offset test

`bench-3x3-45min{R,L}` is the smallest staircase that exists: `N, E, N`, one
diagonal step of 127.279 mm, with `sd45_offset` at one end and `ds45_offset` at
the other. Both offsets have to come out of that one step, so each must be
under 63.6 mm or the geometry does not close.

At the shipped 120/120 it does not close: the planner abandons the diagonal
entirely and drives `ARC_R`, `SPIN_L` instead. At 60/60 it drives `SD45_R`, one
step, `DS45_L`. Same maze, same mouse, and the only thing that changed was a
number -- which makes this the rig that tells you what the offsets really are.

`bench-3x3-45{R,L}` is the same idea one step longer: a two-step diagonal of
254.56 mm. It survives 120/120 with 14.6 mm of free diagonal left between the
turns, against 134.6 mm at 60/60. Run both and you can see where the boundary
actually sits rather than where the model says it should.

## Regenerating

    python3 mkbench.py ../../mazefiles/bench

`mkbench.py` holds the start poses and corridor walks and nothing else. The
walks came from `bench.cpp`, which enumerates every single-corridor maze that
fits in a section from every start pose it allows -- 644 of them in a 3x3 --
plans each with the real planner, and reports which rig shows each turn best:

    make -f build.mk bench
    ./bench --size=3x3 --off=60 --isolate
    ./bench --size=3x3 --off=60 --isolate --start=2,0,N

`--isolate` ranks a rig by how little else is in the route before how often the
turn appears; without it, repetitions win. `--start` pins the pose she will
actually be placed in, so what comes out is the rig to build rather than one of
its mirrors. Neither ranking will ever offer a rig containing a spin, because a
spin means she has stopped dead in the middle of the test and nothing is being
profiled at that moment.

## Checking

`checktxt` reads the shipped ASCII back -- walls and goal -- and **derives the
start pose from the file itself**: a single corridor has exactly two ends, one
of them is the goal, and the other is where she gets put down, heading along
its one opening. So the pose is verified rather than taken on trust, and what
gets checked is the file that goes to the mouse rather than the generator's
idea of it:

    make -f build.mk checktxt
    ./checktxt --off=60 ../../mazefiles/bench/*.txt

`check 0` on every line means the route is drivable. Run it with `--off=120`
too and watch the diagonal rigs fall back to arcs and spins: that is not a bug
in the mazes, it is the current offsets telling you they are too big.

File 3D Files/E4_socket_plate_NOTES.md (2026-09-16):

# E4 sensor socket plate — rev D

Holds four of your existing `Sensor_Housing.STL` parts. The housing drops through the plate and
**seats on the PCB**, so the housing sets the optics and the plate only sets position and azimuth.

Detector optic **7.021 mm** above the seat, emitter **12.743 mm** — emitter on top, 5.72 apart.
Footprint 6.893 across × 8.025 along the beam.

Generated by `E4_socket_plate.py`. Nothing in it is guessed: the board outline, the five 2 mm holes,
the Black Pill and BT header keep-outs and all sixteen lead pads are parsed from
`documents/schematics/E4-blackpill-v2.brd`.

## Placement (70° on the sides) — unchanged since v8

| ch | front face | azim | emitter lead | detector lead |
|----|---|---|---|---|
| SL | (13.50, 91.41) | +70.0° | 19.5 / 26.5 | 12.2 / 12.7 |
| SR | (62.69, 92.23) | -69.5° | 19.0 / 26.5 | 10.7 / 12.7 |
| FL | (4.84, 76.75) | +9.5° | 18.7 / 26.5 | 10.9 / 12.7 |
| FR | (72.13, 76.73) | -10.5° | 18.7 / 26.5 | 10.9 / 12.7 |

Side reach **62.8 mm** against 81.1 as the board is routed — about **×1.67** on the emitter leg —
landing at y = 112.9, **6 mm clear of the forward post**. 70° is the shallowest angle that clears
the post: 60° still lands on it, 65° catches its edge. Change `abs(az)>70.0` in the source to move it.

## How it is held down

**The foot is the motor-mount rail.** Each mount is a 40 × 6 × 15 mm block standing on the board —
the plain white outline on layer 21, x 14–20 running y 14.5–54.5, mirrored at x 57–63 — and it
stands on **one M2 nut per stud**, purely as a spacer.

The plate's foot replaces that nut: **6 × 40 × 1.6 mm** lying inside the white outline, with both
studs through it, and the mount slots straight down on top. Five fixings in all — four studs plus
the apex M2 at (38.5, 98).

> **1.6 mm, not 2.** The wheels are the datum. The axle height above the floor is fixed by the
> wheel and the mount is fixed to the axle, so packing the mount up off the board does not raise
> the mount — it lowers the **board**, and the sensors and ground clearance with it. A 2 mm foot
> would have dropped the optics from 7.0 to 6.6 mm. At exactly one nut thickness nothing moves.

Between foot and nose: stays at foot height for the mount's full length, steps up to the 6.4 mm
plate at y = 54.8 (0.3 mm past the mount's end), then threads the corridor between the board edge
and the Black Pill. Forward of y = 57 it overhangs the board edge by 0.8 mm — free air there — which
widens the pinch from 1.8 to 3.0 mm.

The apex boss runs the full way down to the board. On rev A the edge grippers set the standoff and
the apex bolt was only a locator; with the grippers gone it was left spanning 2 mm of air, and
tightening it would have bowed the nose down.

## Verified

| check | result |
|---|---|
| Beam cones — 33 rays per optic, against the plate **and all four placed housings** | **0 of 264 blocked** |
| Lead paths — every pad reachable from the board up to its lead height | **0 of 16 blocked** |
| Vertices inside a wheel cutout | **0** |
| Material above the foot inside the mount rail (y ≤ 54.8) | **none** |
| Clearance to the Black Pill | **0.6 mm** |
| Narrowest arm section | 3.0 mm wide × 6.4 tall |
| Minimum cross-section, foot to nose | 13 mm² |
| Mesh | watertight, 1 body, ~7 g, 81 × 87 × 8.4 mm |
| Genuine overhang | **0.0 mm²** |

## What rev A got wrong — printed, and every fault caught by eye

Rev A was printed. Four defects came out of it, and **the verification table above passed all four**.

1. **Grippers in the wheel wells.** The board is not a rectangle with a semicircular nose: between
   y 14.5 and 54.5 it steps in to x 11.46 / 65.54 to clear the wheels. The grippers at x 1.0 / 76.0
   sat ~8 mm inside those wells and caught the tyres. The plate had been checked against the real
   outline; the feet were placed against a remembered one.
2. **Board slot too tight** — 1.8 mm nominal for a 1.6 mm PCB. Vertical pockets print near-nominal
   in FDM; a **horizontal** slot loses 0.2–0.4 mm to squish and sag and wants +0.6. No slot in rev D.
3. **The pad hung 0.5 mm into a cutout** at y = 45.0 — four vertices.
4. Earlier still: every optic blind, no lead holes, and a plate straight through the Black Pill,
   because it had been checked against a guessed centred box instead of the library footprint.

The lesson, written down so it stays written down: **this is an optical mount and a fitted part,
not a solid.** Trace rays and lead paths against the plate *and* the parts standing in it, and
check every foot against the parsed outline, never a remembered one. And put it in the slicer.

## Process: MJF PA11 nylon, black — not FDM

Made by JLCPCB's 3D service. HP Multi Jet Fusion, **PA11-HP nylon**, black. A powder bed, not FDM.

### The order, definitively

| field | setting | why |
|---|---|---|
| 3D Technology | **MJF (Nylon)** | Black through the bulk, tough, no orientation or support decisions |
| Material | **PA11-HP Nylon** | **Not the pre-selected PA12-HP.** Isotropic, 50% elongation in every orientation, 1.7× the notched impact, same stiffness, better strength |
| Color | **Black** | PA11 lists black as a *material* colour, not a finish — the part arrives black with nothing added |
| Surface Finish | **No** | The colour is already black. Anything here *adds* to a part whose pockets are dimensionally critical — see below |
| Thread | **No** | All five holes are M2 clearance, not tapped |
| Quantity | **3** | A crash spare and one for the second board |

**Surface Finish must be No, and it will not be.** Choosing PA11 changes what that row offers —
dyeing is how PA12 gets its black, but PA11 *is* black, so the row switches to **Spray Painting** and
pre-fills **Matte / Sky Blue / Exterior Only**. Paint is wrong here twice over: a coat of unknown
thickness onto four pockets sized to 0.50 mm and into two optical trenches whose floors are doing a
job, on a part that is already the colour you want. Turn the row off.

> **Unless the torch test fails.** If the part passes 940 nm — hold it between an emitter and a phone
> camera — then **Matte Black spray, exterior only** is the fix on the next order: paint is
> carbon-pigmented and genuinely opaque where a dye may not be. That is a response to a measurement,
> not a default. A matte coat is tens of microns a side, so drop `FIT` to 0.55–0.60 on a painted order.

**None of this is the default.** A freshly uploaded model lands on **SLA (Resin) / 9600 Resin /
White / Sanding** every time — wrong process, wrong colour, and the one post-process that must not
touch this part. Switching to MJF then pre-selects **PA12-HP**, the wrong nylon. Set every field by
hand on every upload. It is a checklist, not a preference.

### Which nylon

| | PA12-HP *(pre-selected)* | **PA11-HP** | PA12S-HP | PAC-HP |
|---|---|---|---|---|
| Colour | Natural gray, dyed black | **Black, natural gray** | Black, gray | Full colour |
| Tensile | 48 MPa | **52 MPa, XY and Z** | 45 / 43 MPa | not published |
| Elongation at break | 20% | **50%, all orientations** | 12% XY, 5% Z | not published |
| Tensile modulus | 1800 MPa | 1800 MPa | 1700 MPa | not published |
| Notched Izod | 3.6 kJ/m² | **6 / 5 kJ/m²** | 2.5 / 2.0 kJ/m² | not published |
| Tolerance (<100 mm) | ±0.3 mm | ±0.3 mm | ±0.3 mm | ±0.3 mm |
| Minimum wall | 1.0 mm | 1.0 mm | 1.0 mm | **2.0 mm** |
| Sold for | structural, mounting hardware | structural, **snap-fits**, housings | — | toys, craft prototypes |

**PA11-HP wins on every mechanical axis and one that matters more than all of them: it is
isotropic.** 52 MPa in XY *and* Z, 50% elongation in all orientations, 6 and 5 kJ/m² notched.
PA12-HP publishes no split, but HP's own datasheet puts PA12 at 19% in plane and 12% across the
build axis; PA12S collapses to 5%. On a powder bed the supplier nests the parts — orientation is not
a field on the order form — so with PA12 every copy is a roll of the dice as to whether a 3 mm arm
lands with its weak direction loaded. With PA11 there is no weak direction.

It is also 2.5× the elongation and 1.7× the notched impact of the default, at the same stiffness and
better strength, in a material sold for snap-fits. For a part that will be driven into walls, that is
the whole argument.

**PAC-HP is out twice over:** it is the full-colour decorative grade sold for toys, and its **2 mm
minimum wall would reject the 1.6 mm foot outright**. PA12S-HP, despite the "New" badge, is the
weakest of the three engineering nylons on every published figure.

> **PA11 costs more and drinks more.** Bio-based, from castor oil, and typically priced above PA12 —
> irrelevant on a 7 g part, worth a glance on the quote. It absorbs somewhat more moisture than PA12,
> so expect marginally more dimensional drift with humidity, and being more ductile it will creep a
> little more under the foot's clamp load. Neither changes the recommendation.

### Why nylon and not resin

The same supplier offers SLA and on paper the engineering resins look better — tighter, stiffer,
sold for exactly this kind of bracket:

| | MJF PA11-HP | SLA 9000HE |
|---|---|---|
| Colour | **Black**; natural gray | White |
| Tolerance (<100 mm) | ±0.3 mm | ±0.2 mm |
| Tensile | 52 MPa | 41–61 MPa |
| Elongation at break | **50%** | 7–12% |
| Modulus | 1800 MPa | 2705–2875 MPa flexural |
| Minimum wall | > 1.0 mm | > 0.8 mm |

**Colour settles it.** The engineering resins are white. A white plate wrapped around four IR optics
is a diffuse reflector at 940 nm millimetres from every detector — cross-talk that cannot be fixed
afterwards short of painting it, and paint puts thickness back into the pockets. Black resins exist
in the catalogue but they are the general-purpose and fine-detail grades. **The tough resins are not
black and the black resins are not tough.**

Two entries deserve honesty. The tolerance gap is **0.1 mm**, not the order of magnitude a generic
SLA-vs-MJF table implies — that gap belongs to in-house industrial SLA, not to this supplier. It
would buy `FIT` 0.40 instead of 0.50, about 0.7° of azimuth. And the resin is genuinely **1.6×
stiffer**, a real benefit for a 40 mm cantilever. If this part tolerated white, resin would win.

The rest: SLS is the same nylon family with no advantage unless cheaper. WJP is fine-detail and
brittle. FDM gets nothing a home printer does not. SLM and BJ are metal — 7 g of nylon becomes ~20 g
of aluminium or ~55 g of steel, and a specular reflector next to the sensors.

### Process limits vs this part

| JLC MJF PA11-HP | value | this part |
|---|---|---|
| Dimensional tolerance | ±0.3 mm (<100 mm), ±0.4% above | `FIT` 0.50 sized against it |
| Minimum wall | > 1.0 mm | 1.6 mm foot, 3.0 mm arm — ok |
| Tensile (XY / Z) | 52 / 52 MPa | — |
| Elongation | 50%, all orientations | — |
| Modulus | 1800 MPa | — |
| Notched Izod (XY / Z) | 6 / 5 kJ/m² | — |

No enclosed voids, so no trapped powder. No model change needed for this supplier or material.

### Pocket clearance

`FIT` is **0.50 mm**, opened from the 0.30 chosen for FDM. At ±0.3 mm process tolerance, 0.30
nominal has a worst case of zero — four pockets that will not take a housing without filing, after a
three-day turnaround. 0.50 gives 0.2 at the tight end (assemblable) and 0.8 at the loose end (held
by the epoxy). It is the tight end that has no recovery.

Opening it costs azimuth: slack *c* over the housing's 8.025 mm grip allows about `atan(c/8.025)` —
2.1° at 0.30, 3.6° at 0.50, 4.3° at 0.60. Not free at 70° on the sides, where 65° already catches
the post's edge. Survivable only because **the angle is set at glue-up**: the pocket holds the
housing square while the epoxy goes off, and the aim comes from sighting the emitter on a phone
camera and peaking the detector on a live reading. The pocket is a fixture, not a datum. 0.30 is the
FDM number if a different process is ever used.

### Other MJF consequences

- **Orientation and supports are not ours to choose.** A powder bed needs neither. The "feet down,
  no supports, 0.0 mm² overhang" notes apply to a home FDM test print and nothing else.
- **The nylons are about half the stiffness of PLA** (1800 MPa vs ~3500) at similar strength. The
  3.0 × 6.4 mm arm deflects further but bends and returns rather than snapping.
- **The foot creeps rather than cracks.** Nylon under sustained clamp load goes slack slowly instead
  of splitting. Re-check the mount bolts after the first few runs.
- **The black sits over a grey bulk.** MJF nylon comes off the machine grey (carbon black from the
  fusing agent, through the bulk); PA11's black is a supplier colour on top of that rather than
  pigment mixed into the powder. A black that looks black in daylight need not absorb at 940 nm, so
  the grey bulk may be doing most of the real work. **Torch test on arrival:** hold the part between an emitter and a phone camera — phone
  sensors see 940 nm — and see if it glows.

## Printing and fitting

- **MJF:** nothing to specify — no orientation choice, no supports, no perimeters.
- **FDM test print:** feet down flat on the bed (the plate body's 2 mm underside is standoff over the
  SMDs, not material), no supports, at least four perimeters. Black PLA blocks 940 nm well, but FDM
  light-pipes along layer boundaries.

1. Take the four nuts out from under the motor mounts, lift the mounts off the studs.
2. Lay the plate on, feet over the studs, apex M2 at (38.5, 98) with a nut under the board.
3. Put the mounts back straight onto the feet, then the two nuts and the daughterboard above each.
4. Drop each housing through its pocket until it seats on the PCB, check azimuth, epoxy in the pocket.
5. Fit the parts and form the leads as on the current mouse.

**Do not lean on the driver.** The foot is a printed part taking the mount's clamp load where a
steel nut used to. If it crushes, the axles dip and the sensor height goes with them.

## Tight spots, honestly

- **Detector leads are the binding constraint.** SL uses 12.2 mm of a 12.70 mm minimum. Bend right
  at the housing's rear face and trim only after the lead is formed.
- Pads sit **0.4–2 mm behind** the rear face. Enough for the lead to drop, not enough to be casual.
- Pocket clearance `FIT` is **0.50 mm** on both axes, set for MJF. 0.30 is the FDM number.
- The arm is **3.0 mm wide × 6.4 mm tall** at the Black Pill pinch. That is the governing section.
- Free tilt inside the housing bores (±4–6° emitter, ±8° detector, Ch 5) is unchanged. The plate
  fixes the housing's angle, not the part's angle within it.
- `motormountfinal.stl` in this folder is the mount as sent for printing, drawn **lying down** for
  the bed: 40 long × 15 high × 6 wide. Standing up it is the 6 mm rail on the silkscreen.
- **Rev D has not been printed.** Rev A was, and see above.

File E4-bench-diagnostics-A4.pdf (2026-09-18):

# E4 — cell template, 1:1

### lay it in a cell, square it to the posts, mark through the four midpoints

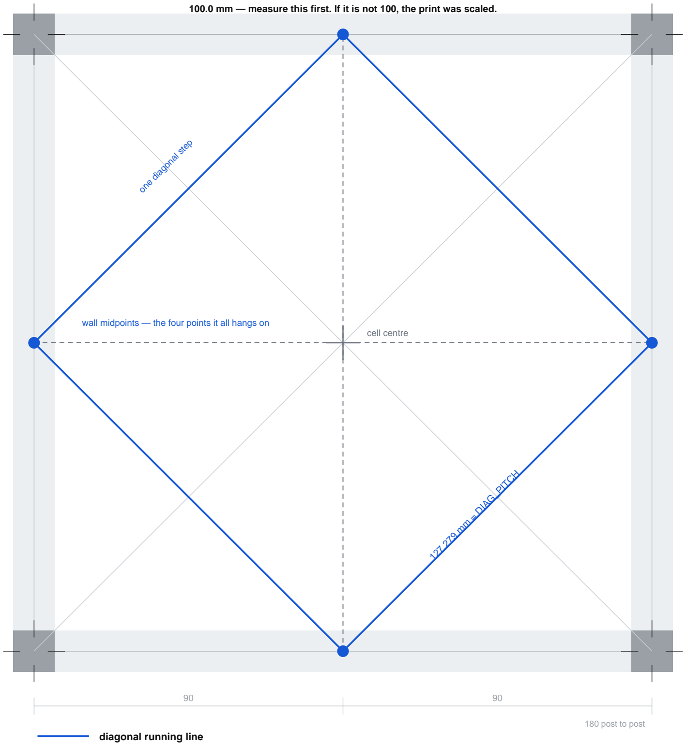
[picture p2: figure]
127.279 mm = DIAG_PITCH; one diagonal step; cell centre; 180 post to post; diagonal running line

wall midpoints — the four points it all hangs on

joins the four wall midpoints. The lane she is on between an SD45 and a DS45.

orthogonal centrelines
the straight lanes — 90 mm from the boundary, 84 mm clear of a wall face.

corner to corner
post to post. For checking squareness and 45 by eye — she never drives on it. To mark it out: find each wall midpoint (90 mm from either post) and join the four. That diamond passes a post on every
side without touching one, which is the whole point of it. The cell centre is NOT on it — that is what the 45s have to bridge.

100.0 mm — measure this first. If it is not 100, the print was scaled.

E4 · bench diagnostics | 1:1 cell template

# E4 — turn tuning

one page per row. Every number below is derived from the row itself — nothing here was measured.

row | name | ω | R | tangent | +½ cell | needs | has | out by | page
1 | SS90ER | 170 | 101 | 101 | — | 101 | 100 | -1 | 3
0 | SS90EL | 170 | 101 | 101 | — | 101 | 100 | -1 | 4
3 | SS90R | 170 | 101 | 101 | — | 101 | 100 | -1 | 5
2 | SS90L | 170 | 101 | 101 | — | 101 | 100 | -1 | 6
7 | SD45R | 95 | 181 | 75 | 90 | 165 | 120 | -45 | 7
6 | SD45L | 95 | 181 | 75 | 90 | 165 | 120 | -45 | 8
8 | DS45L | 95 | 181 | 75 | — | 75 | 120 | +45 | 9
9 | DS45R | 95 | 181 | 75 | — | 75 | 120 | +45 | 10
14 | DD90L | 273 | 63 | 63 | — | 63 | 63 | agrees | 11
15 | DD90R | 273 | 63 | 63 | — | 63 | 63 | agrees | 12
5 | SS180R | 191 | 90 | — | — | — | 90 | +0 | 13
4 | SS180L | 191 | 90 | — | — | — | 90 | +0 | 14

Four of the twelve rows already agree with themselves. The 45s do not, and they cannot both be right while they
share one number: an SD45 is booked in at a cell centre while its two lanes cross at the wall midpoint half a cell
earlier, so it wants 165, and a DS45 turns at its own lattice point and wants 75. Both hold 120 today.

A running order that does not waste an afternoon: gyro first, then the 90s (rows 0–3) because they are the only rows that have ever met a floor and they are the check on everything else. Then SD45 and DS45 separately — never chained — because a lateral error out of the first moves the start of the second. Then DD90, which has 127 mm either side of it instead of 180 and is the tightest thing she does. The 180 last: its omega is forced by the cell pitch, so there
is nothing to search for.

Trim the OFFSET, not omega. Omega sets the radius, and the radius has to fit the space it is turning in; the offset is free. Both move her, at the rates each page gives.

Each page carries the exact three lines to type into Turn tuning, with the corrected offset already in them. S saves the table to EEPROM; nothing is permanent until it does.

E4 · turn tuning · one row per page | contents

# Row 1 — SS90ER, a 90 out of a straight

the search 90 — she stops and senses either side of it, so it need not chain

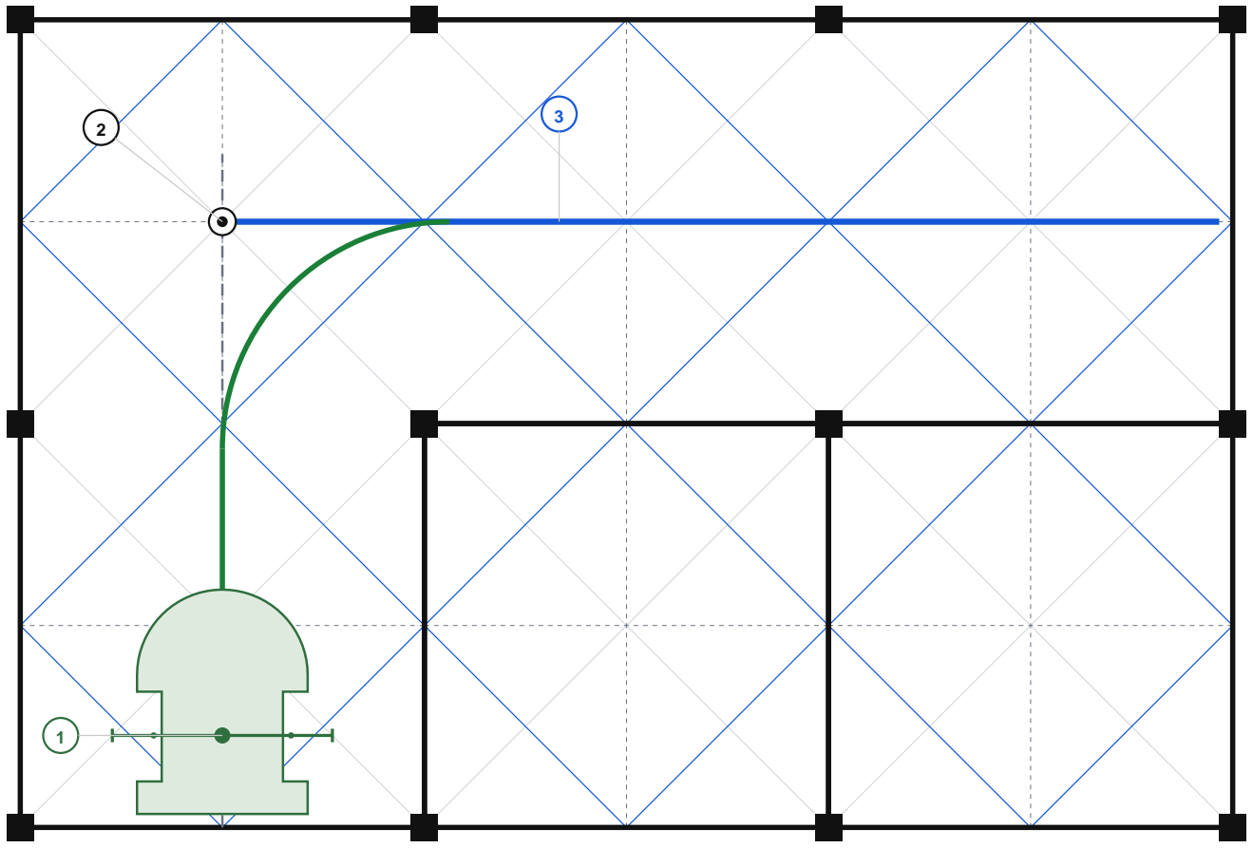
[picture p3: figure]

the lane — measure to this | | the turn it should drive
SEL,1 POS,1 ARC,300,-90,170,2500,101,90 | — the table holds 100; this line corrects it
commanded speed | 300 mm/s
omega | 170 deg/s | the only thing that sets the radius
R = v / omega | 101 mm | instantaneous; alpha's ramps make the real arc a little wider
tangent R·tan(45°) | 101 mm | either side of where the lanes cross
+ half cell | 0 mm | two straight lanes cross AT the cell centre, so nothing is added
entry_offset it needs | 101 mm | so the arc is tangent to both lanes
entry_offset it has | 100 mm | out by -1 mm
lead-in it drives now | 129 mm | out of the start cell, then the arc
lead-in once corrected | 128 mm | she starts turning 1 mm earlier

What to read off the floor

1 Back her against the wall, facing north. The marked line across her is the AXLE LINE — her centre of rotation, and the point every distance on this page is measured from.
2 The two lanes cross AT the cell centre for a 90, so there is no half cell to add here — the tangent is the whole offset.
3 Coming out she should be on the blue line and square to it. Measure the wall gap either side; they should match.
This row already agrees with itself: the offset it has and the offset the radius wants are the same number, so there is no drawn error to
chase. What is left is the floor.
1 mm of entry offset moves her 1.00 mm. 1 deg/s of omega moves her 0.59 mm. Trim the OFFSET: omega sets the radius, and the radius has to fit the space.
E4 · turn tuning · one row per page | SS90ER

# Row 0 — SS90EL, a 90 out of a straight

the search 90 — she stops and senses either side of it, so it need not chain

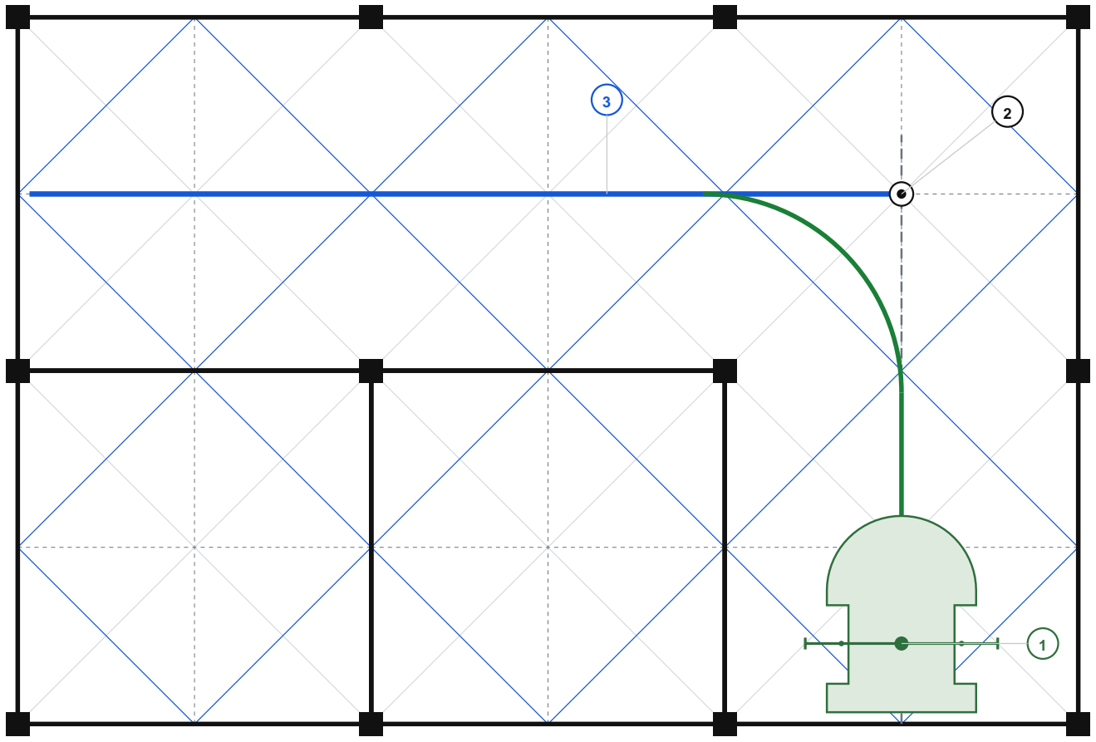
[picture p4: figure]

the lane — measure to this | | the turn it should drive
SEL,0 POS,1 ARC,300,90,170,2500,101,90 | — the table holds 100; this line corrects it
commanded speed | 300 mm/s
omega | 170 deg/s | the only thing that sets the radius
R = v / omega | 101 mm | instantaneous; alpha's ramps make the real arc a little wider
tangent R·tan(45°) | 101 mm | either side of where the lanes cross
+ half cell | 0 mm | two straight lanes cross AT the cell centre, so nothing is added
entry_offset it needs | 101 mm | so the arc is tangent to both lanes
entry_offset it has | 100 mm | out by -1 mm
lead-in it drives now | 129 mm | out of the start cell, then the arc
lead-in once corrected | 128 mm | she starts turning 1 mm earlier

What to read off the floor

1 Back her against the wall, facing north. The marked line across her is the AXLE LINE — her centre of rotation, and the point every distance on this page is measured from.
2 The two lanes cross AT the cell centre for a 90, so there is no half cell to add here — the tangent is the whole offset.
3 Coming out she should be on the blue line and square to it. Measure the wall gap either side; they should match.
This row already agrees with itself: the offset it has and the offset the radius wants are the same number, so there is no drawn error to
chase. What is left is the floor.
1 mm of entry offset moves her 1.00 mm. 1 deg/s of omega moves her 0.59 mm. Trim the OFFSET: omega sets the radius, and the radius has to fit the space.
E4 · turn tuning · one row per page | SS90EL

# Row 3 — SS90R, a 90 out of a straight

the speed-run 90 — this one has to chain, wall midpoint to wall midpoint

the lane — measure to this | | the turn it should drive
SEL,3 POS,1 ARC,300,-90,170,2500,101,90 | — the table holds 100; this line corrects it
commanded speed | 300 mm/s
omega | 170 deg/s | the only thing that sets the radius
R = v / omega | 101 mm | instantaneous; alpha's ramps make the real arc a little wider
tangent R·tan(45°) | 101 mm | either side of where the lanes cross
+ half cell | 0 mm | two straight lanes cross AT the cell centre, so nothing is added
entry_offset it needs | 101 mm | so the arc is tangent to both lanes
entry_offset it has | 100 mm | out by -1 mm
lead-in it drives now | 129 mm | out of the start cell, then the arc
lead-in once corrected | 128 mm | she starts turning 1 mm earlier

What to read off the floor

1 Back her against the wall, facing north. The marked line across her is the AXLE LINE — her centre of rotation, and the point every distance on this page is measured from.
2 The two lanes cross AT the cell centre for a 90, so there is no half cell to add here — the tangent is the whole offset.
3 Coming out she should be on the blue line and square to it. Measure the wall gap either side; they should match.
This row already agrees with itself: the offset it has and the offset the radius wants are the same number, so there is no drawn error to
chase. What is left is the floor.
1 mm of entry offset moves her 1.00 mm. 1 deg/s of omega moves her 0.59 mm. Trim the OFFSET: omega sets the radius, and the radius has to fit the space.
E4 · turn tuning · one row per page | SS90R

# Row 2 — SS90L, a 90 out of a straight

the speed-run 90 — this one has to chain, wall midpoint to wall midpoint

the lane — measure to this | | the turn it should drive
SEL,2 POS,1 ARC,300,90,170,2500,101,90 | — the table holds 100; this line corrects it
commanded speed | 300 mm/s
omega | 170 deg/s | the only thing that sets the radius
R = v / omega | 101 mm | instantaneous; alpha's ramps make the real arc a little wider
tangent R·tan(45°) | 101 mm | either side of where the lanes cross
+ half cell | 0 mm | two straight lanes cross AT the cell centre, so nothing is added
entry_offset it needs | 101 mm | so the arc is tangent to both lanes
entry_offset it has | 100 mm | out by -1 mm
lead-in it drives now | 129 mm | out of the start cell, then the arc
lead-in once corrected | 128 mm | she starts turning 1 mm earlier

What to read off the floor

1 Back her against the wall, facing north. The marked line across her is the AXLE LINE — her centre of rotation, and the point every distance on this page is measured from.
2 The two lanes cross AT the cell centre for a 90, so there is no half cell to add here — the tangent is the whole offset.
3 Coming out she should be on the blue line and square to it. Measure the wall gap either side; they should match.
This row already agrees with itself: the offset it has and the offset the radius wants are the same number, so there is no drawn error to
chase. What is left is the floor.
1 mm of entry offset moves her 1.00 mm. 1 deg/s of omega moves her 0.59 mm. Trim the OFFSET: omega sets the radius, and the radius has to fit the space.
E4 · turn tuning · one row per page | SS90L

# Row 7 — SD45R, straight onto the diagonal

one turn on its own — the heavy blue line is the thing she has to end up on

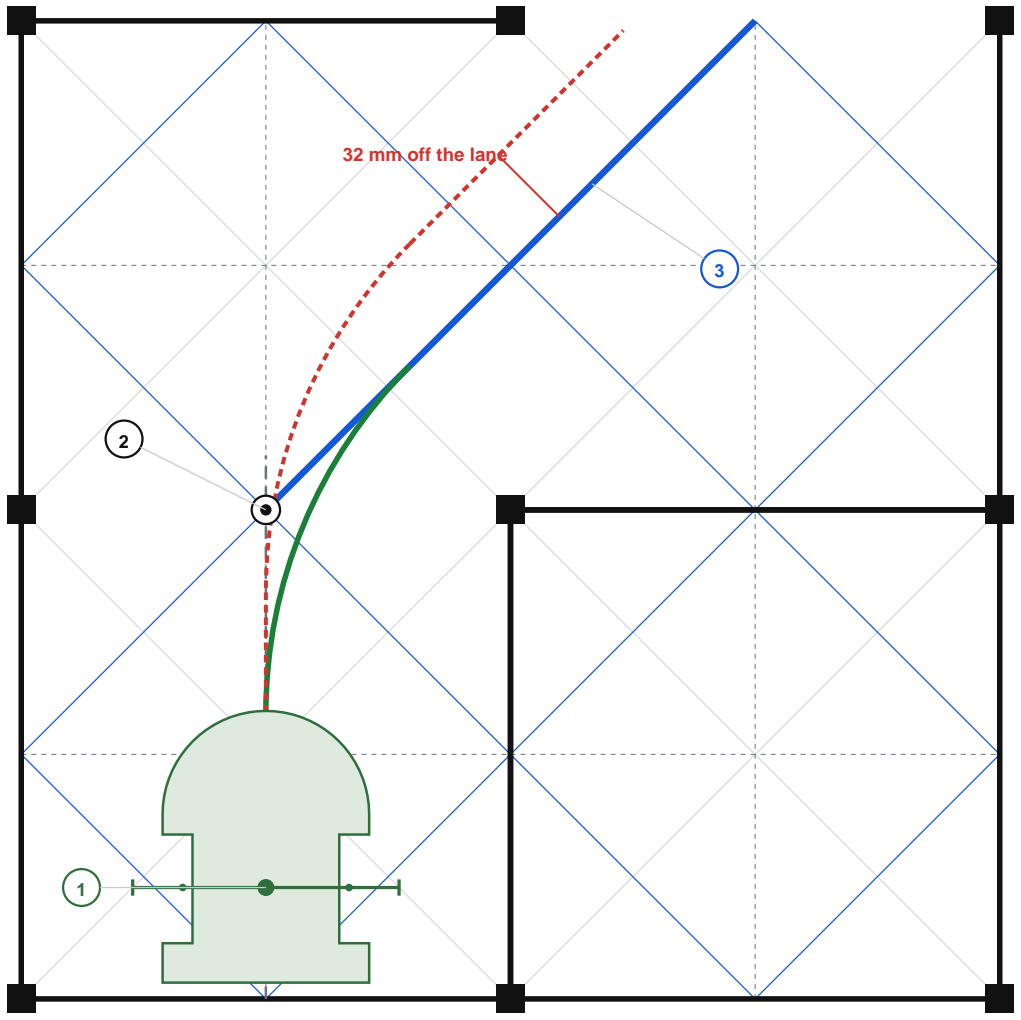
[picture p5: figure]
32 mm off the lane

the lane — measure to this | the turn it should drive | what the table drives today
SEL,7 POS,1 ARC,300,-45,95,2500,165,90 | — the table holds 120; this line corrects it
commanded speed | 300 mm/s
omega | 95 deg/s | the only thing that sets the radius
R = v / omega | 181 mm | instantaneous; alpha's ramps make the real arc a little wider
tangent R·tan(22.5°) | 75 mm | either side of where the lanes cross
+ half cell | 90 mm | a straight lane meets a diagonal at the WALL MIDPOINT, not the cell centre
entry_offset it needs | 165 mm | so the arc is tangent to both lanes
entry_offset it has | 120 mm | out by -45 mm
lead-in it drives now | 109 mm | out of the start cell, then the arc
lead-in once corrected | 64 mm | she starts turning 45 mm earlier

What to read off the floor

1 Back her against the wall, facing north. The marked line across her is the AXLE LINE — her centre of rotation, and the point every distance on this page is measured from. 35 mm of chassis sits behind it.
2 She should already be turning by the time she reaches the wall midpoint — that, not the cell centre, is where the lanes cross.
3 Coming out of the arc she should be ON the blue line and parallel to it. That is the whole measurement; ignore where she stops.
Too LATE (offset too small) and she overshoots to the far side of the line, away from the post; too EARLY and she cuts inside it, close to
that post. She is LATE today, by 45 mm of offset.
1 mm of entry offset moves her 0.71 mm. 1 deg/s of omega moves her 0.56 mm. Trim the OFFSET: omega sets the radius, and the radius has to fit the space.
E4 · turn tuning · one row per page | SD45R

# Row 6 — SD45L, straight onto the diagonal

one turn on its own — the heavy blue line is the thing she has to end up on

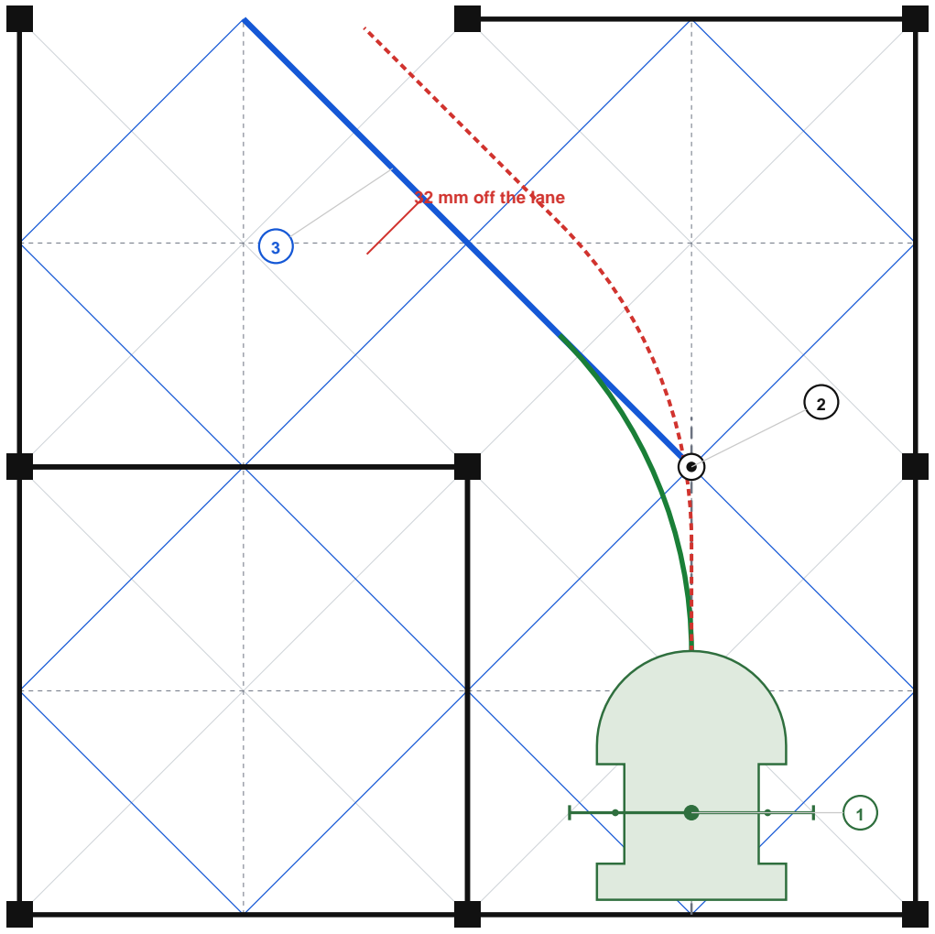
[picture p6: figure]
32 mm off the lane

the lane — measure to this | the turn it should drive | what the table drives today
SEL,6 POS,1 ARC,300,45,95,2500,165,90 | — the table holds 120; this line corrects it
commanded speed | 300 mm/s
omega | 95 deg/s | the only thing that sets the radius
R = v / omega | 181 mm | instantaneous; alpha's ramps make the real arc a little wider
tangent R·tan(22.5°) | 75 mm | either side of where the lanes cross
+ half cell | 90 mm | a straight lane meets a diagonal at the WALL MIDPOINT, not the cell centre
entry_offset it needs | 165 mm | so the arc is tangent to both lanes
entry_offset it has | 120 mm | out by -45 mm
lead-in it drives now | 109 mm | out of the start cell, then the arc
lead-in once corrected | 64 mm | she starts turning 45 mm earlier

What to read off the floor

1 Back her against the wall, facing north. The marked line across her is the AXLE LINE — her centre of rotation, and the point every distance on this page is measured from. 35 mm of chassis sits behind it.
2 She should already be turning by the time she reaches the wall midpoint — that, not the cell centre, is where the lanes cross.
3 Coming out of the arc she should be ON the blue line and parallel to it. That is the whole measurement; ignore where she stops.
Too LATE (offset too small) and she overshoots to the far side of the line, away from the post; too EARLY and she cuts inside it, close to
that post. She is LATE today, by 45 mm of offset.
1 mm of entry offset moves her 0.71 mm. 1 deg/s of omega moves her 0.56 mm. Trim the OFFSET: omega sets the radius, and the radius has to fit the space.
E4 · turn tuning · one row per page | SD45L

# Row 8 — DS45L, diagonal back onto a straight

she is placed ON the diagonal for this one — there is no wall to back up against

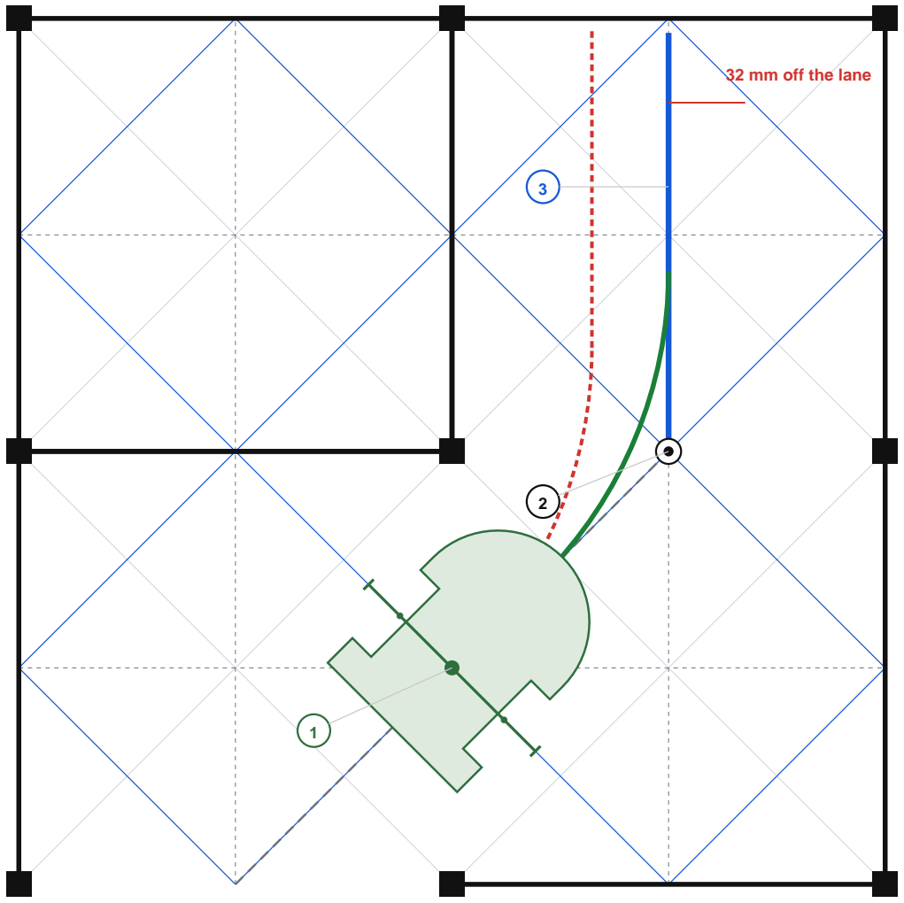
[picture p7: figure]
32 mm off the lane

the lane — measure to this | the turn it should drive | what the table drives today
SEL,8 POS,1 ARC,300,45,95,2500,75,90 | — the table holds 120; this line corrects it
commanded speed | 300 mm/s
omega | 95 deg/s | the only thing that sets the radius
R = v / omega | 181 mm | instantaneous; alpha's ramps make the real arc a little wider
tangent R·tan(22.5°) | 75 mm | either side of where the lanes cross
+ half cell | 0 mm | she turns AT her lattice point here, so nothing is added
entry_offset it needs | 75 mm | so the arc is tangent to both lanes
entry_offset it has | 120 mm | out by +45 mm
lead-in it drives now | 7 mm | along the diagonal, then the arc
lead-in once corrected | 52 mm | she starts turning 45 mm later

What to read off the floor

1 Put her down so the AXLE LINE — the line through the motors, which is her centre of rotation — crosses the blue diagonal at the marked point, square to it. Her body will straddle the gap; that is right.
2 The diagonal and the straight lane cross AT the wall midpoint, which is also the point the offset is measured from.
3 Coming out she should be on the centreline of the column above, and square to it.
The diagonal runs 63.6 mm from each post centre, so 55 mm clear of the nearest post CORNER either side — a 110 mm channel for a 61.2 mm track. Square her carefully: a degree of yaw here is worth more than a millimetre of position.
Too LATE (offset too small) and she overshoots to the far side of the line, away from the post; too EARLY and she cuts inside it, close to
that post. She is EARLY today, by 45 mm of offset.
1 mm of entry offset moves her 0.71 mm. 1 deg/s of omega moves her 0.56 mm. Trim the OFFSET: omega sets the radius, and the radius has to fit the space.
E4 · turn tuning · one row per page | DS45L

# Row 9 — DS45R, diagonal back onto a straight

she is placed ON the diagonal for this one — there is no wall to back up against

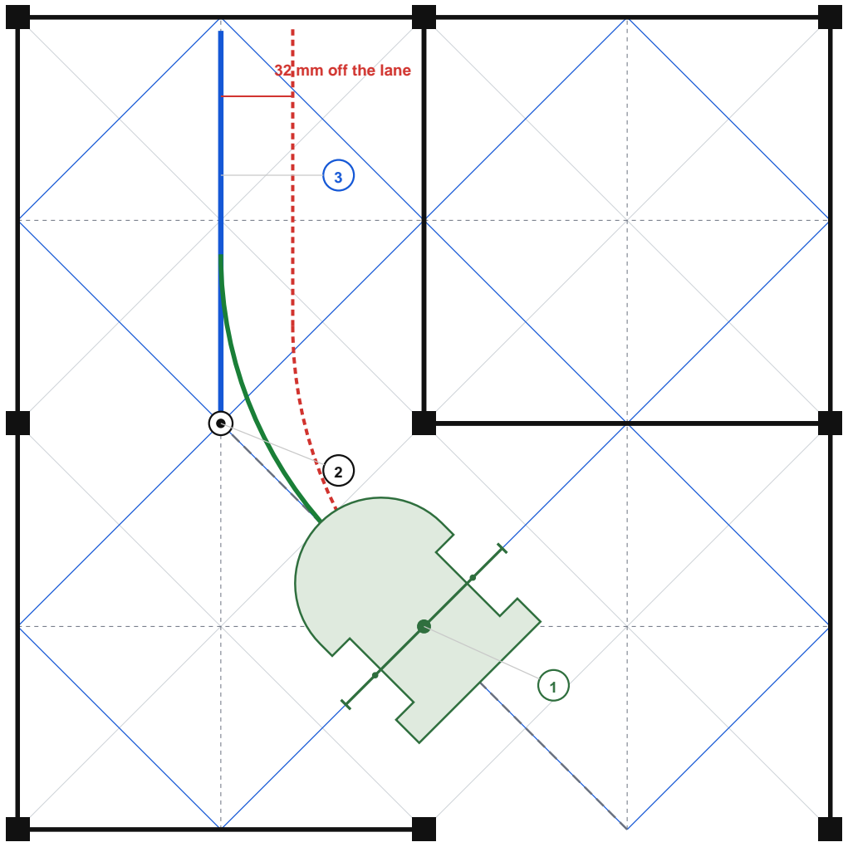
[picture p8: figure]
32 mm off the lane

the lane — measure to this | the turn it should drive | what the table drives today
SEL,9 POS,1 ARC,300,-45,95,2500,75,90 | — the table holds 120; this line corrects it
commanded speed | 300 mm/s
omega | 95 deg/s | the only thing that sets the radius
R = v / omega | 181 mm | instantaneous; alpha's ramps make the real arc a little wider
tangent R·tan(22.5°) | 75 mm | either side of where the lanes cross
+ half cell | 0 mm | she turns AT her lattice point here, so nothing is added
entry_offset it needs | 75 mm | so the arc is tangent to both lanes
entry_offset it has | 120 mm | out by +45 mm
lead-in it drives now | 7 mm | along the diagonal, then the arc
lead-in once corrected | 52 mm | she starts turning 45 mm later

What to read off the floor

1 Put her down so the AXLE LINE — the line through the motors, which is her centre of rotation — crosses the blue diagonal at the marked point, square to it. Her body will straddle the gap; that is right.
2 The diagonal and the straight lane cross AT the wall midpoint, which is also the point the offset is measured from.
3 Coming out she should be on the centreline of the column above, and square to it.
The diagonal runs 63.6 mm from each post centre, so 55 mm clear of the nearest post CORNER either side — a 110 mm channel for a 61.2 mm track. Square her carefully: a degree of yaw here is worth more than a millimetre of position.
Too LATE (offset too small) and she overshoots to the far side of the line, away from the post; too EARLY and she cuts inside it, close to
that post. She is EARLY today, by 45 mm of offset.
1 mm of entry offset moves her 0.71 mm. 1 deg/s of omega moves her 0.56 mm. Trim the OFFSET: omega sets the radius, and the radius has to fit the space.
E4 · turn tuning · one row per page | DS45R

# Row 14 — DD90L, the diagonal changes hand

the only turn that begins and ends on a diagonal — and the only one with 127 mm, not 180, either side of it

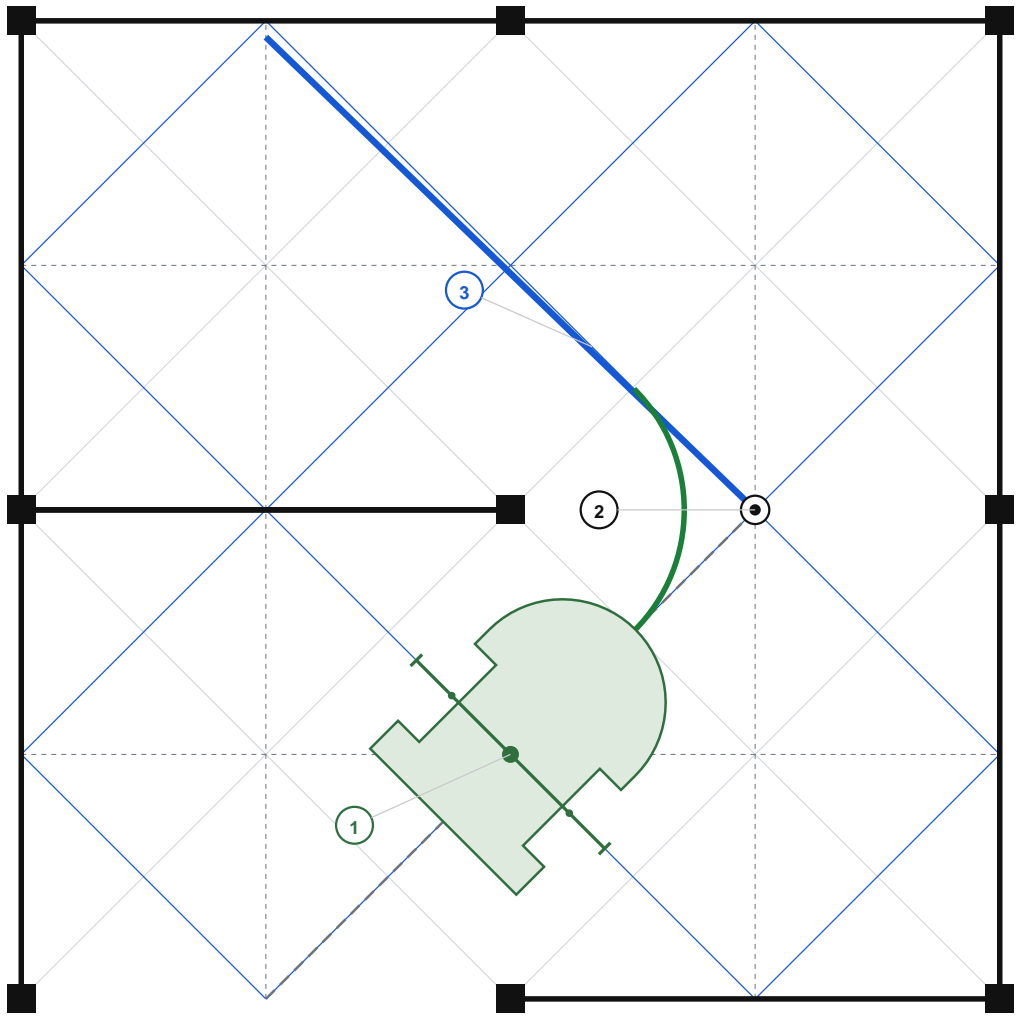
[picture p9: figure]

the lane — measure to this | | the turn it should drive

## SEL,14 POS,1 ARC,300,90,273,2500,63,90

commanded speed | 300 mm/s
omega | 273 deg/s | the only thing that sets the radius
R = v / omega | 63 mm | instantaneous; alpha's ramps make the real arc a little wider
tangent R·tan(45°) | 63 mm | either side of where the lanes cross
+ half cell | 0 mm | two diagonals cross AT the wall midpoint, so nothing is added
entry_offset it needs | 63 mm | so the arc is tangent to both lanes
entry_offset it has | 63 mm | agrees
lead-in it drives now | 64 mm | along the diagonal, then the arc

What to read off the floor

1 Put her down so the AXLE LINE — the line through the motors, which is her centre of rotation — crosses the blue diagonal at the marked point, square to it. Her body will straddle the gap; that is right.
2 She turns at the wall midpoint, and the step either side is 127.279 mm — not 180. That is what makes this the tight one.
3 Coming out she should be on the OTHER blue diagonal and parallel to it, having passed the post without touching it.
The diagonal runs 63.6 mm from each post centre, so 55 mm clear of the nearest post CORNER either side — a 110 mm channel for a 61.2 mm track. Square her carefully: a degree of yaw here is worth more than a millimetre of position.
This row already agrees with itself: the offset it has and the offset the radius wants are the same number, so there is no drawn error to
chase. What is left is the floor.
1 mm of entry offset moves her 1.00 mm. 1 deg/s of omega moves her 0.23 mm. Trim the OFFSET: omega sets the radius, and the radius has to fit the space.
E4 · turn tuning · one row per page | DD90L

# Row 15 — DD90R, the diagonal changes hand

the only turn that begins and ends on a diagonal — and the only one with 127 mm, not 180, either side of it

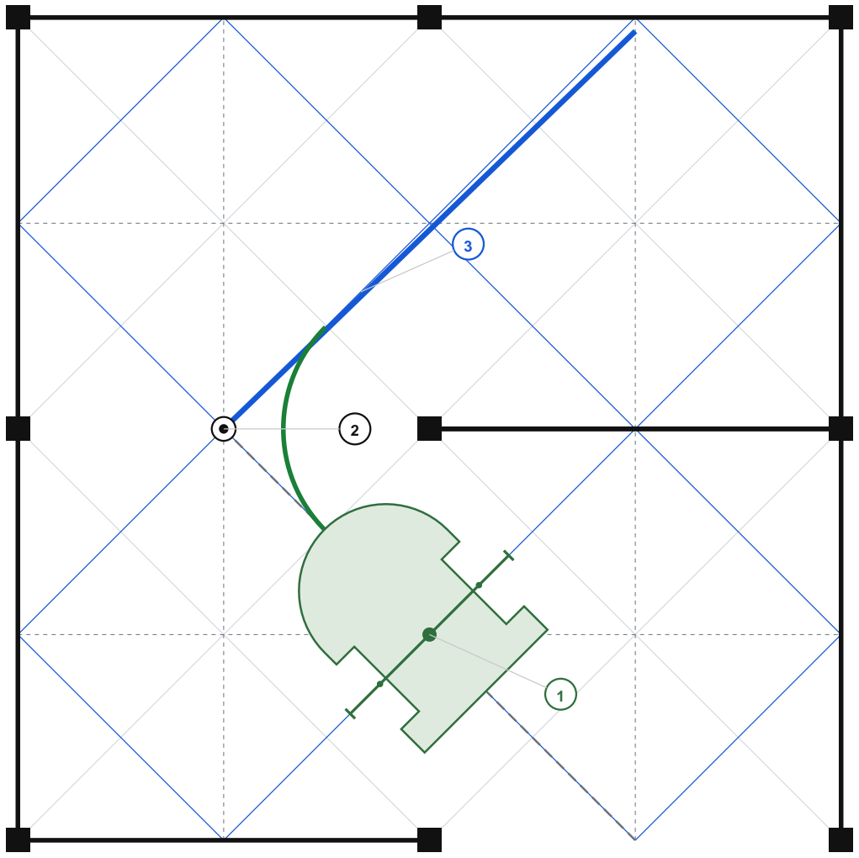
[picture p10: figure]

the lane — measure to this | | the turn it should drive

## SEL,15 POS,1 ARC,300,-90,273,2500,63,90

commanded speed | 300 mm/s
omega | 273 deg/s | the only thing that sets the radius
R = v / omega | 63 mm | instantaneous; alpha's ramps make the real arc a little wider
tangent R·tan(45°) | 63 mm | either side of where the lanes cross
+ half cell | 0 mm | two diagonals cross AT the wall midpoint, so nothing is added
entry_offset it needs | 63 mm | so the arc is tangent to both lanes
entry_offset it has | 63 mm | agrees
lead-in it drives now | 64 mm | along the diagonal, then the arc

What to read off the floor

1 Put her down so the AXLE LINE — the line through the motors, which is her centre of rotation — crosses the blue diagonal at the marked point, square to it. Her body will straddle the gap; that is right.
2 She turns at the wall midpoint, and the step either side is 127.279 mm — not 180. That is what makes this the tight one.
3 Coming out she should be on the OTHER blue diagonal and parallel to it, having passed the post without touching it.
The diagonal runs 63.6 mm from each post centre, so 55 mm clear of the nearest post CORNER either side — a 110 mm channel for a 61.2 mm track. Square her carefully: a degree of yaw here is worth more than a millimetre of position.
This row already agrees with itself: the offset it has and the offset the radius wants are the same number, so there is no drawn error to
chase. What is left is the floor.
1 mm of entry offset moves her 1.00 mm. 1 deg/s of omega moves her 0.23 mm. Trim the OFFSET: omega sets the radius, and the radius has to fit the space.
E4 · turn tuning · one row per page | DD90R

# Row 5 — SS180R, the hairpin

not a dead end — she comes back down the NEXT lane, so the lateral step has to be exactly one cell

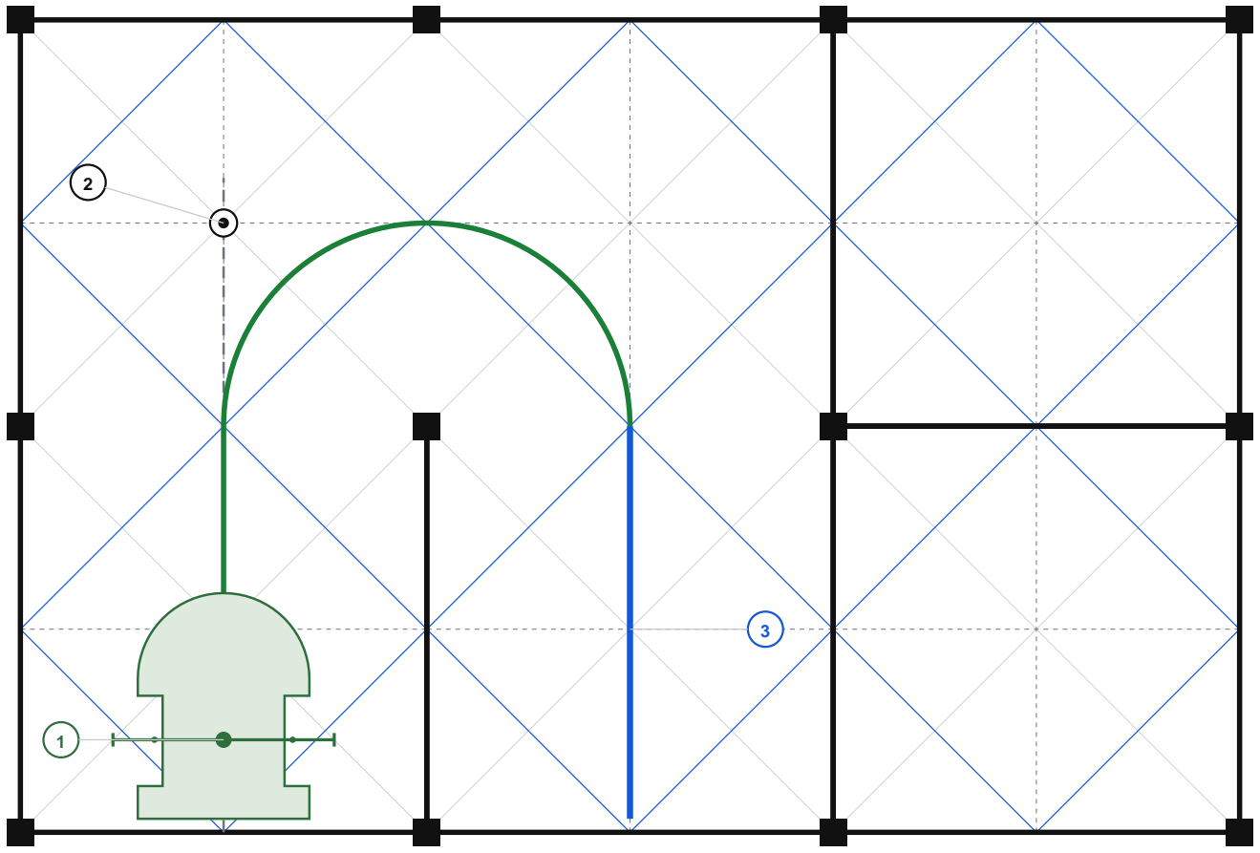
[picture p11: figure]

the lane — measure to this | | the turn it should drive

## SEL,5 POS,1 ARC,300,-180,191,2500,90,90

commanded speed | 300 mm/s
omega | 191 deg/s | and this one is NOT free — see below
R = v / omega | 90 mm | instantaneous; alpha's ramps make the real arc wider
lateral step 2R | 180 mm | has to be 180 — one cell — or she lands off the lane
out by | 0 mm | — it lands on the lane
entry_offset | 90 mm | sets only how far up the cell she does it
lead-in it drives | 139 mm | out of the start cell, then the arc

What to read off the floor

1 Back her against the wall, facing north. The line across her is the AXLE LINE, her centre of rotation and the datum for everything here. 2 entry_offset is measured back from this cell centre; the arc starts 90 mm before it. 3 She must come back down the blue line — the next lane over, 180 mm across. Measure the wall gap on both sides.
OMEGA IS NOT FREE ON THIS ROW. A 180 of radius R steps her sideways by 2R, and that has to be exactly one cell.
2R = 180 forces R = 90 and omega = 191 deg/s at 300 mm/s. 1 deg/s moves her 0.94 mm; the offset moves her not at all.
E4 · turn tuning · one row per page | SS180R

# Row 4 — SS180L, the hairpin

not a dead end — she comes back down the NEXT lane, so the lateral step has to be exactly one cell

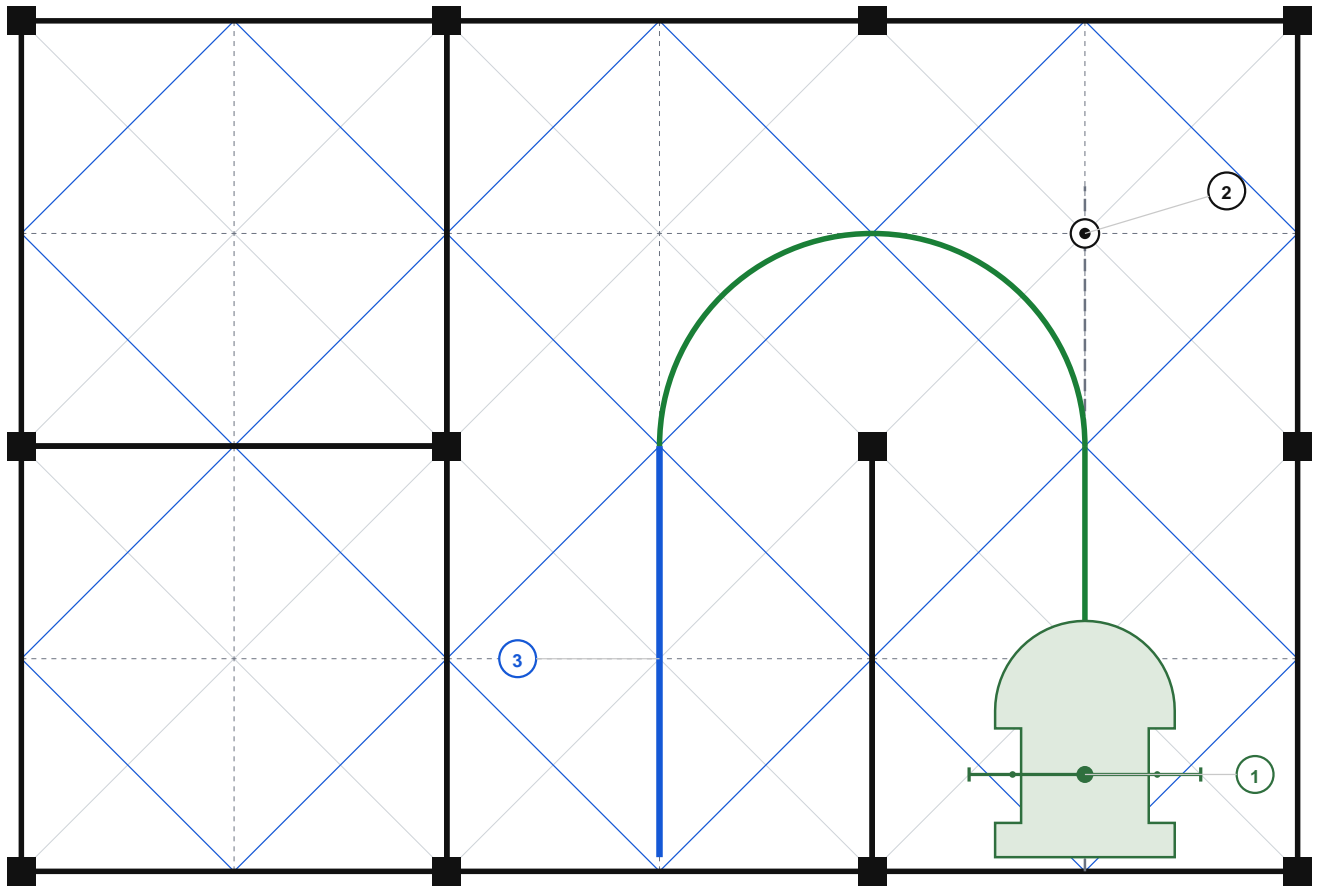
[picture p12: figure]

the lane — measure to this | | the turn it should drive

## SEL,4 POS,1 ARC,300,180,191,2500,90,90

commanded speed | 300 mm/s
omega | 191 deg/s | and this one is NOT free — see below
R = v / omega | 90 mm | instantaneous; alpha's ramps make the real arc wider
lateral step 2R | 180 mm | has to be 180 — one cell — or she lands off the lane
out by | 0 mm | — it lands on the lane
entry_offset | 90 mm | sets only how far up the cell she does it
lead-in it drives | 139 mm | out of the start cell, then the arc

What to read off the floor

1 Back her against the wall, facing north. The line across her is the AXLE LINE, her centre of rotation and the datum for everything here. 2 entry_offset is measured back from this cell centre; the arc starts 90 mm before it. 3 She must come back down the blue line — the next lane over, 180 mm across. Measure the wall gap on both sides.
OMEGA IS NOT FREE ON THIS ROW. A 180 of radius R steps her sideways by 2R, and that has to be exactly one cell.
2R = 180 forces R = 90 and omega = 191 deg/s at 300 mm/s. 1 deg/s moves her 0.94 mm; the offset moves her not at all.
E4 · turn tuning · one row per page | SS180L

# The post loop — four chained 90s, driven as one circle

the rig that pins omega for a chainable 90, and shows heading error a tenth of a degree at a time

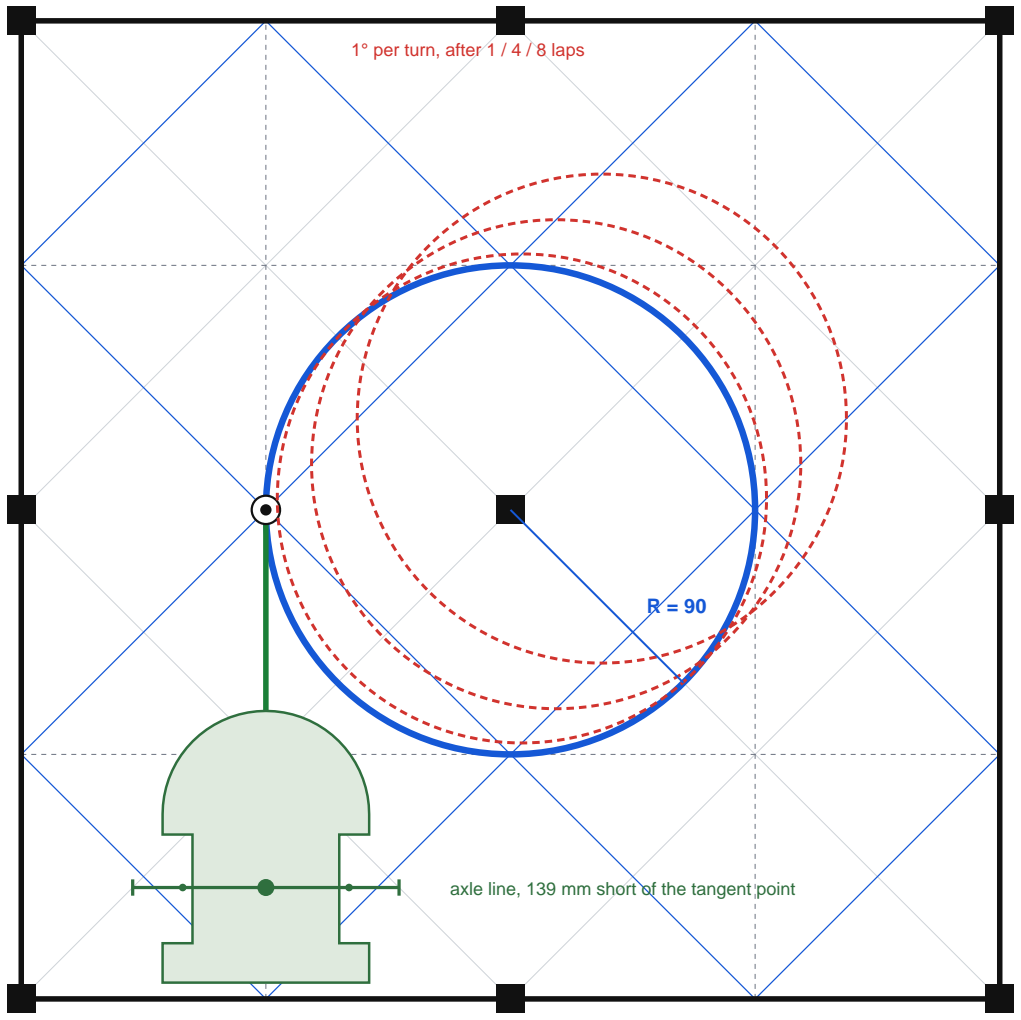
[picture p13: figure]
1° per turn, after 1 / 4 / 8 laps

the 90 mm circle — draw this round the post | the run-in, tangent to it | what drift looks like
| axle line, 139 mm short of the tangent point
LOOP,8,191,2500,1,300 | then run Post loop (Calibration, or BT key A)
commanded speed | 300 mm/s
omega | 191 deg/s | NOT free: R = v/omega and R has to be 90
R = v / omega | 90 mm | half a cell — the quarter circle that chains
one lap | 565 mm | 2πR. Odometry over N laps gives R back with no ruler.
lead-in from the wall | 139 mm | 49 + 90: out of the start cell to the tangent point
at the SS90 row's 170 | 635 mm | R 101: a lap 70 mm long, and 22 mm of overlap between consecutive turns
and with the ramps in | ~700 mm | the zigzag figure — which is why driving it continuously is the cleaner test
drift per lap | 6 mm | for one degree of heading error per turn

What to read off the floor

Four chained same-hand 90s of radius 90 ARE a circle centred on a post: the arc centre sits 90 mm to her right, which is the post, and it is the same point every quarter. So this rig and “four chained turns” are the same experiment, and because she
drives it continuously there are no ramps between the quarters — the ideal R = v/omega applies and omega is pinned at 191.

OVER A CLOSED LAP EVERYTHING EXCEPT HEADING CANCELS. The four local frames sit at 0, 90, 180 and 270 degrees, so a consistent radius error, offset error or tangential lag sums to zero. A heading error does not: the frames precess, the lap stops closing,
and the centre walks about 6 mm a lap per degree per turn. Eight laps turn a tenth of a degree into five millimetres.

So: omega sets the SIZE of the circle — read it off the drawn one, or off odometry. Alpha and the gyro scale set the DRIFT of its centre. Tune omega until she tracks the circle, then alpha until the centre stops walking. The gyro will report the
commanded angle either way, because the loop closes on it; the floor is the only witness.
E4 · turn tuning · one row per page | post loop

# Rows 10–13 — the 135s

### why there is no page for them yet

A 135 turns a straight onto a diagonal the long way round, or back off it. The lanes still cross at a wall midpoint, so SD135 carries the same half cell an SD45 does. What it does not have is room.

The tangent of a 135 turn is R·tan(67.5°) = 2.414R — nearly six times an SD45's. At the table's omega of 191 deg/s, R is 90 mm and the tangent is 217 mm. Add the half cell and an SD135 would have to start turning 307 mm before the cell it is booked in at, which is most of two cells back, through a wall.

To make the tangent fit inside one cell the radius has to come down to about 37 mm, which at 300 mm/s is omega 464 deg/s. That is a spin with the wheels rolling, and the lateral acceleration goes with it.

So the 135s stay as slots. The planner does not emit them, nothing drives them, and the four rows in the table are arithmetic holding a place. When they are wanted, they want their own speed as well as their own radius — which is a different page from any of these.

E4 · turn tuning · one row per page | SD135 / DS135

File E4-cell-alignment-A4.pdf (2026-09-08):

axle

mouse footprint - centred (76 x 100 mm)

FRONT WALL

BACK WALL (mouse backs against this)

168 mm clear (wall inner faces) | 12 mm wall

# E4 - Cell Alignment Template

1:1 print jig - square the walls and centre the mouse. Standard 180 mm cell, 12 mm walls.

0 | 50 | 100

SCALE CHECK: this bar must measure 100 mm. Print at ACTUAL SIZE / 100% - NOT 'Fit to page'/'Shrink to fit'.

Prints on A4 or US Letter. Lay on the floor, align the four walls to the grey bands, then place the mouse on the dashed outline (axle on the centre).

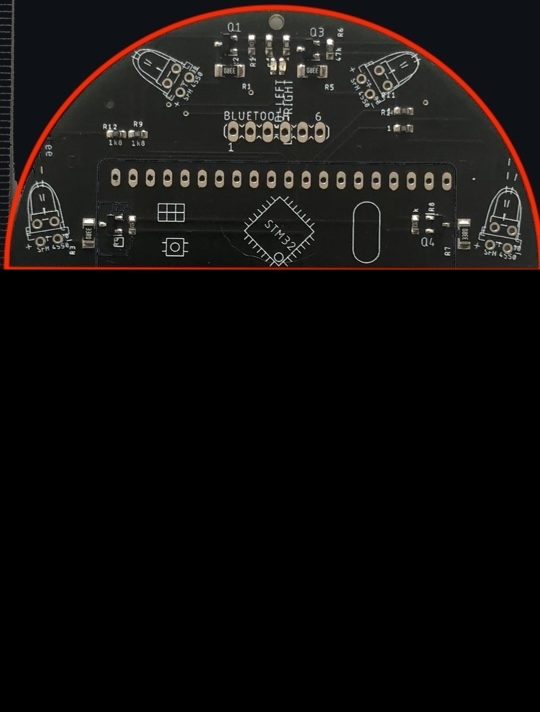
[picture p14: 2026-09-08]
board.jpg

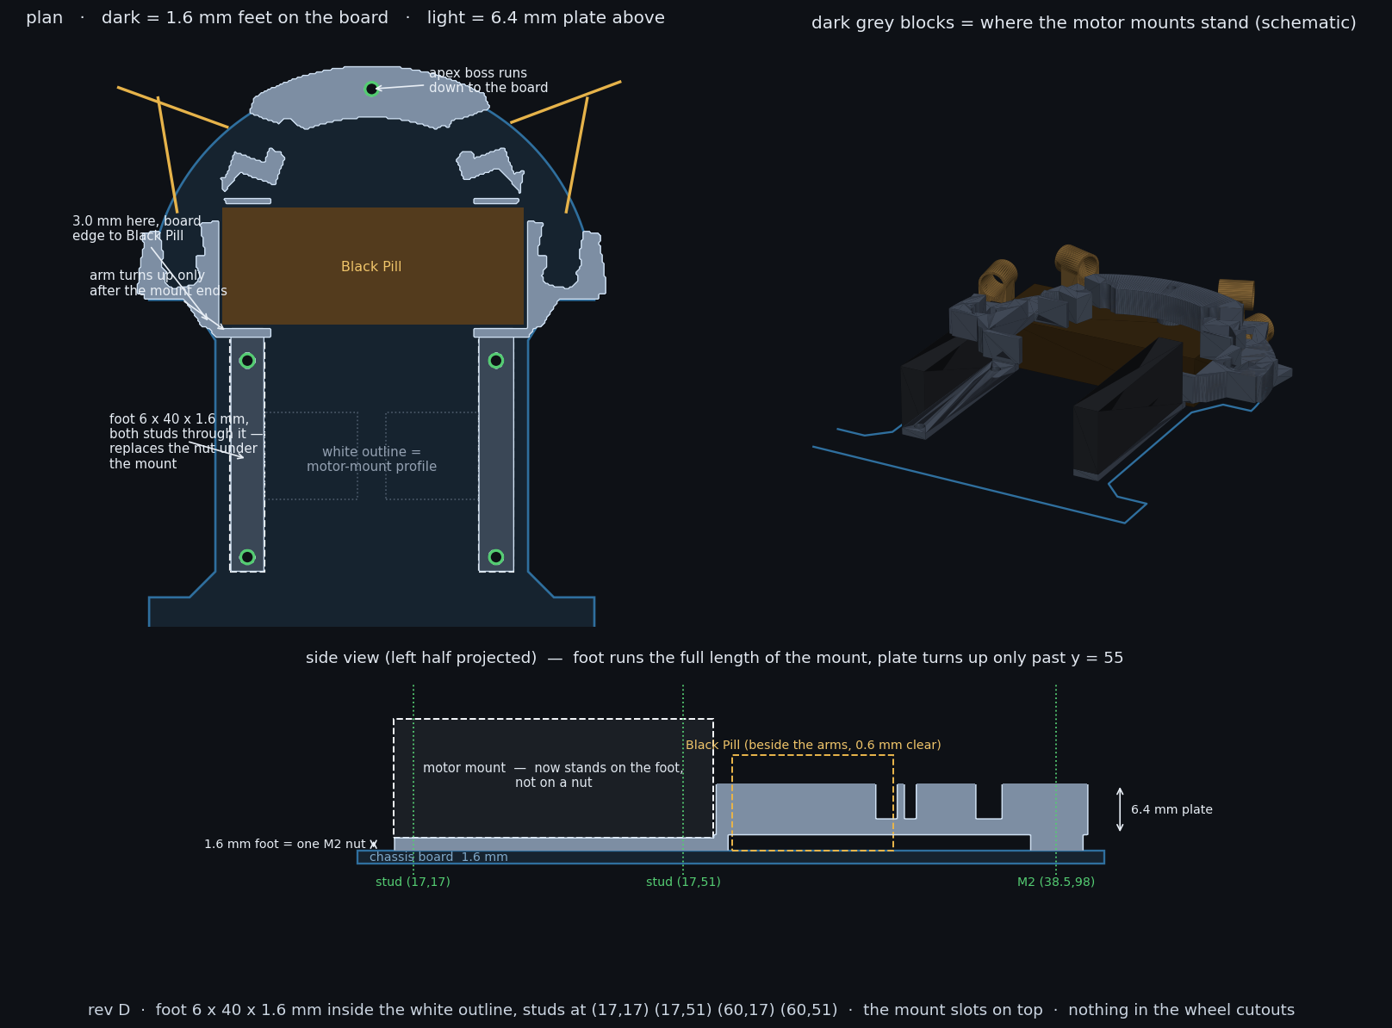
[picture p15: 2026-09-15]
3D Files/E4_socket_plate_revD.png

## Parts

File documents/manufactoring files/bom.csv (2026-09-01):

Qty | Designator | Footprint | Comment | LCSC Part # (optional) | Description (optional)
1 | U$7 | BLACK_PILL | do not populate |  | stm32 board
2 | LED-LEFT, LED-RIGHT | SML0603 |  | C125098 | green SMD leds
1 | BLUETOOTH | MA06-1 | do not populate |  | HC05 board
2 | M-LEFT, M-RIGHT | 2X03 | do not populate |  | headers
2 | UB1,UB2 | TACTILE-PTH | do not populate |  | push button switch
4 | R14, R15, R16,R21 | 0603-RES |  | C269701 | SMD resistor 0603 package 10k
4 | R9, R10, R11,R12 | 0603-RES |  | C269444 | SMD resistor 0603 package 1k8
4 | R17, R18, R19,R20 | 0603-RES |  | C269704 | SMD resistor 0603 package 1k
4 | R1, R3, R5, R7 | 1206 |  | C325941 | SMD resistor 0603 package 33 ohm
5 | R2, R4, R6, R8, R13 | 0603-RES |  | C269715 | SMD resistor 0603 package 47k
1 | U$3 | DRV8833 | do not populate |  | motor driver board
1 | U$1 | E4_SPI-IIC | do not populate |  | display board
4 | IR-FRONTLEFT, IR-FRONTRIGHT, IR-SIDELEFT, IR-SIDERIGHT | EMITTER | do not populate |  | IR emitters
4 | Q1, Q2, Q3, Q4 | SOT96P237X111-3N |  | C15310 | SMD sot23 package FDV301N
4 | DET-FRONTLEFT, DET-FRONTRIGHT, DET-SIDELEFT, DET-SIDERIGHT | RECEIVER | do not populate |  | IR detectors
1 | S1 | TL3XPO | do not populate |  | Tiny Switch
1 | U$4 | BUCK3TO9-HORIZONTAL | do not populate |  | BUCK3TO9BUCK3TO9-HORIZONTAL
1 | U$5 | BUCK3TO5-H | do not populate |  | BUCK3TO5
1 | U$8 | 6410-03 | do not populate |  | 3V3-CONV3V3CONV
1 | X1 | 53047-02 | do not populate |  | 53047-02

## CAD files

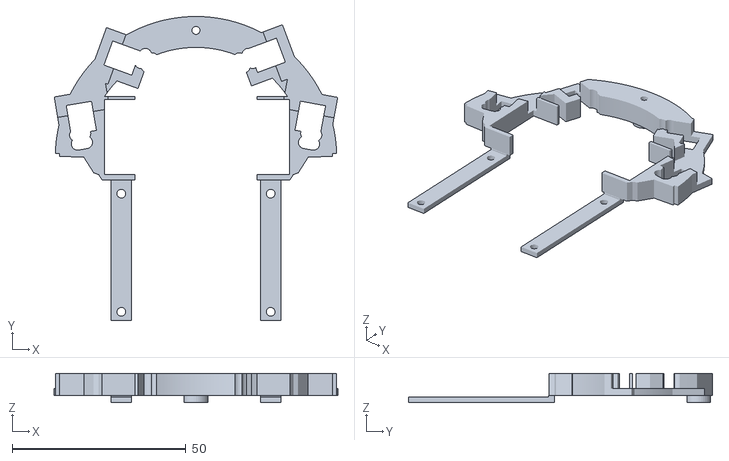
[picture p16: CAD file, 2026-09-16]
3D Files/E4_socket_plate.stl
81.6 x 87.5 x 8.40

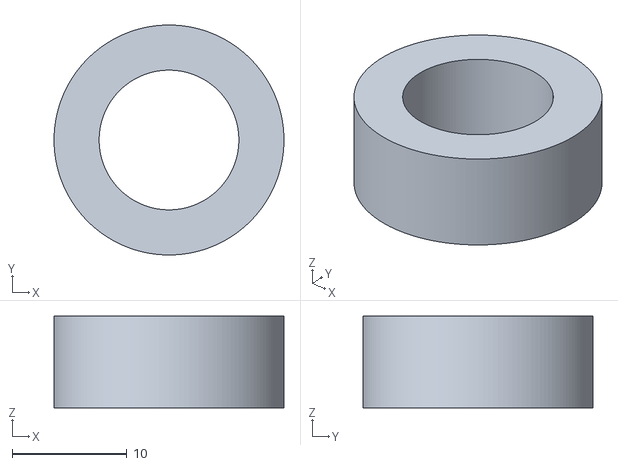
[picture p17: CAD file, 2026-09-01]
3D Files/wheel-19.5mm.stl
20.0 x 20.0 x 8.00

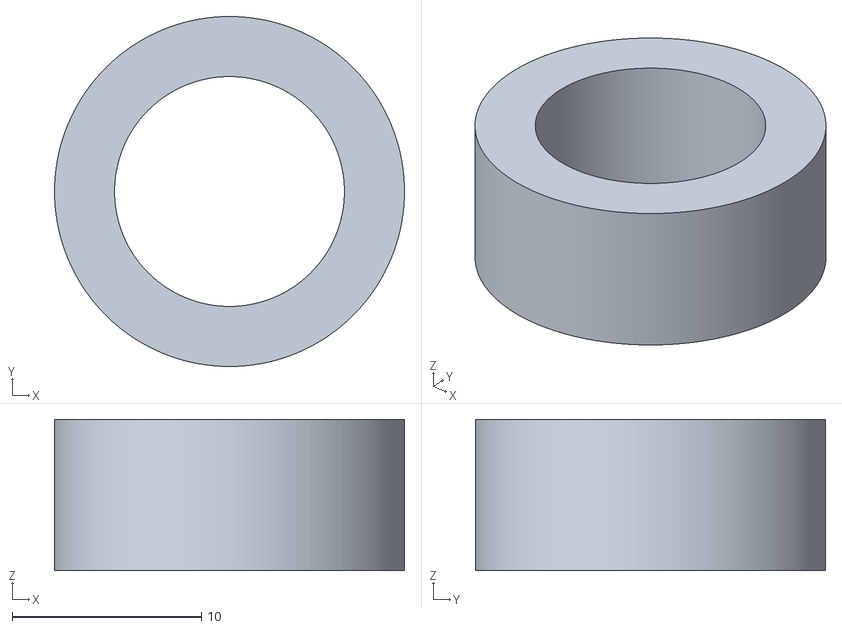
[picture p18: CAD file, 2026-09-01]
3D Files/Wheel185mm.stl
18.5 x 18.5 x 8.00

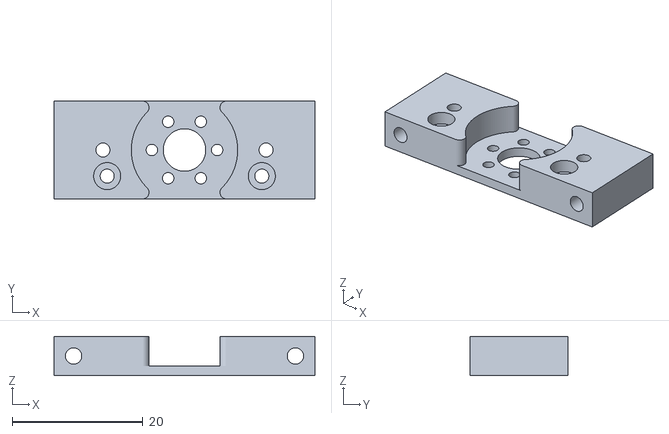
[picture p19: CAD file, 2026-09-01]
3D Files/motormountfinal.stl
40.0 x 15.0 x 6.00

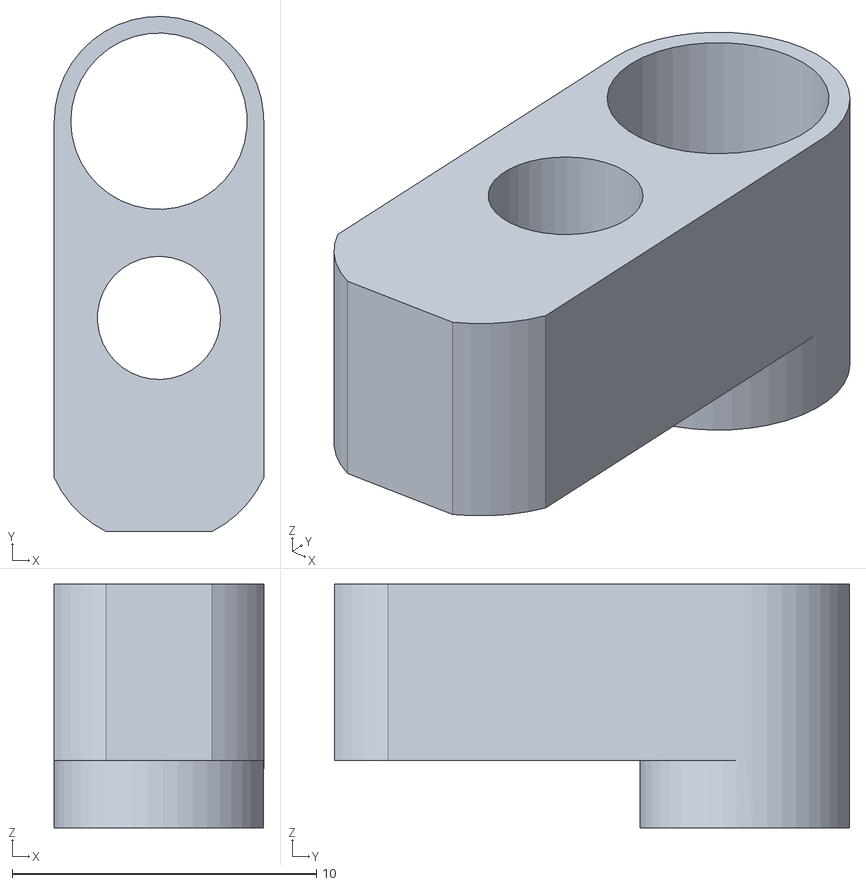
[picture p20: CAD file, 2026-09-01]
3D Files/SensorHousing.stl
6.89 x 16.9 x 8.03

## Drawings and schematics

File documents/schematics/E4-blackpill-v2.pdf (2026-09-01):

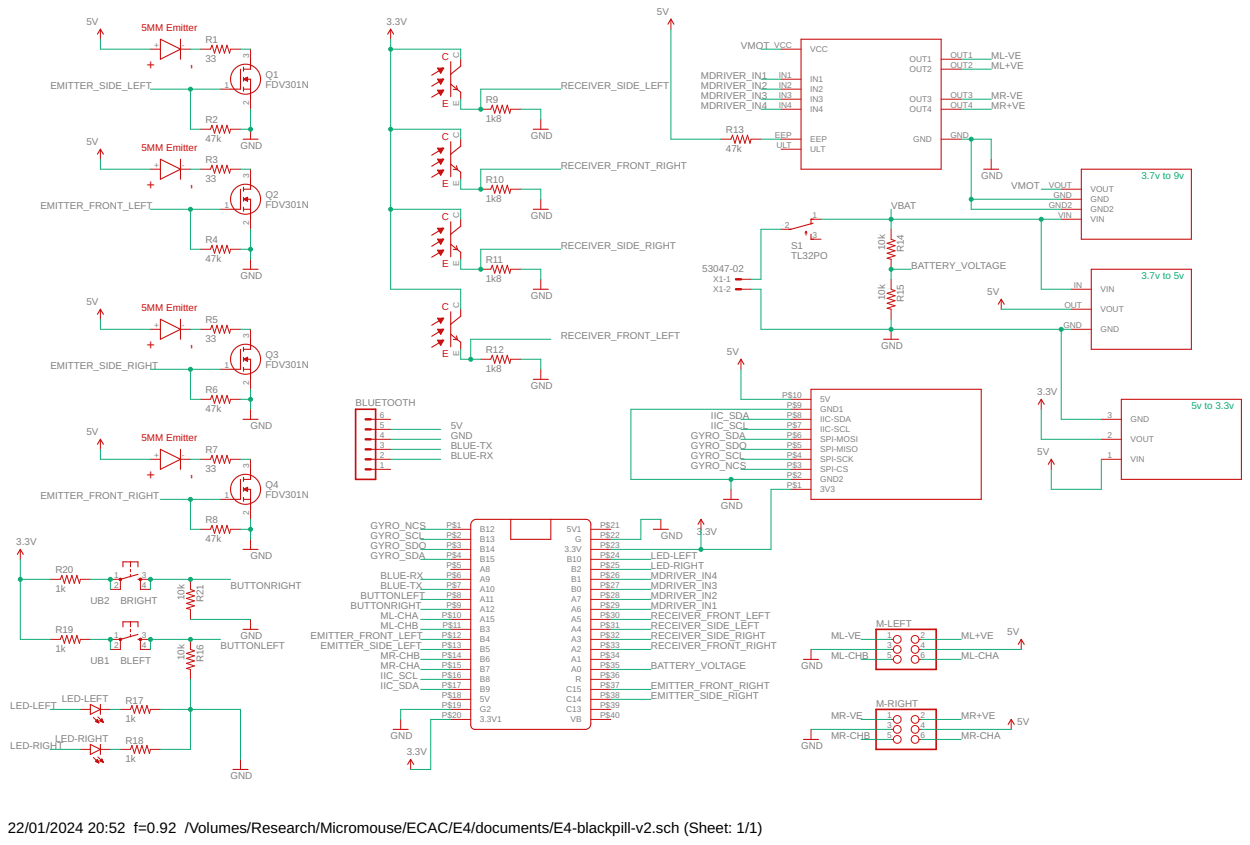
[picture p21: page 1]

22/01/2024 20:52 f=0.92 /Volumes/Research/Micromouse/ECAC/E4/documents/E4-blackpill-v2.sch (Sheet: 1/1)

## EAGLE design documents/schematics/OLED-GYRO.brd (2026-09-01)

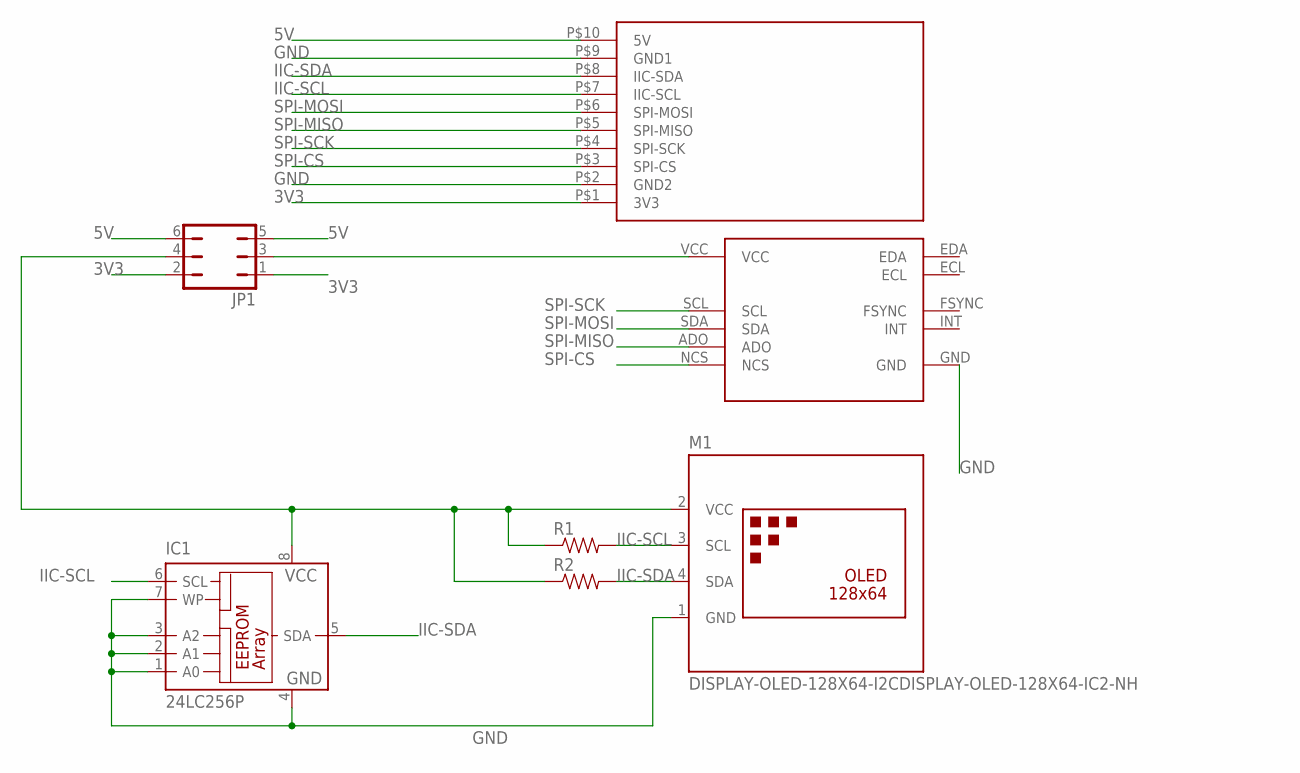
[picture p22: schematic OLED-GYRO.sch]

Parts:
IC1: 24LC256P; DIL8
JP1: JP3Q
M1: DISPLAY-OLED-128X64-I2CDISPLAY-OLED-128X64-IC2-NH; DISPLAY-OLED-128X64-I2C_NH
R1, R2: RESISTORPTH-1/4W; AXIAL-0.4
U$1: E4_SPI-IIC
U$2: MPU-9250/6500; MPU9265

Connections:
3V3: JP1.1, JP1.2, U$1.P$1 (3V3)
5V: JP1.5, JP1.6, U$1.P$10 (5V)
GND: IC1.1 (A0), IC1.2 (A1), IC1.3 (A2), IC1.4 (GND), IC1.7 (WP), M1.1 (GND), U$1.P$2 (GND2), U$1.P$9 (GND1), U$2.GND
IIC-SCL: IC1.6 (SCL), M1.3 (SCL), R1.P$2 (2), U$1.P$7 (IIC-SCL)
IIC-SDA: IC1.5 (SDA), M1.4 (SDA), R2.P$2 (2), U$1.P$8 (IIC-SDA)
unnamed: JP1.3, U$2.VCC
unnamed: IC1.8 (VCC), JP1.4, M1.2 (VCC), R1.P$1 (1), R2.P$1 (1)
SPI-CS: U$1.P$3 (SPI-CS), U$2.NCS
SPI-MISO: U$1.P$5 (SPI-MISO), U$2.ADO
SPI-MOSI: U$1.P$6 (SPI-MOSI), U$2.SDA
SPI-SCK: U$1.P$4 (SPI-SCK), U$2.SCL

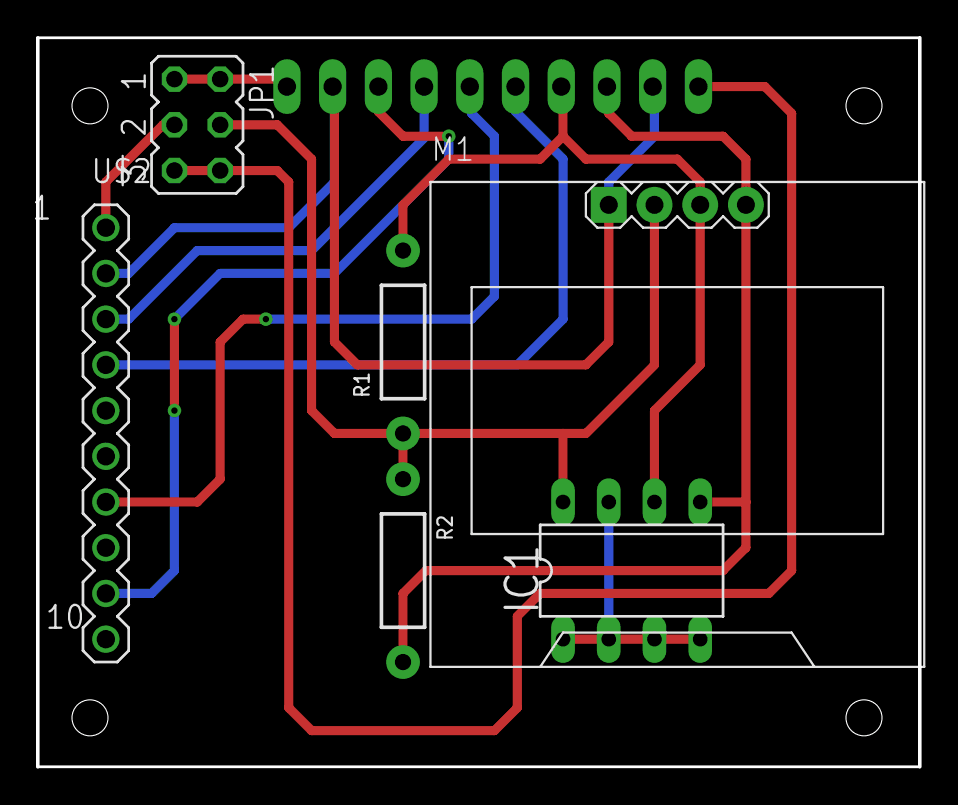
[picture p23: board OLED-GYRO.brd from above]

Board: 2 copper layers, 49.0 x 40.5 mm, 7 parts (0 on the bottom side), 11 nets.

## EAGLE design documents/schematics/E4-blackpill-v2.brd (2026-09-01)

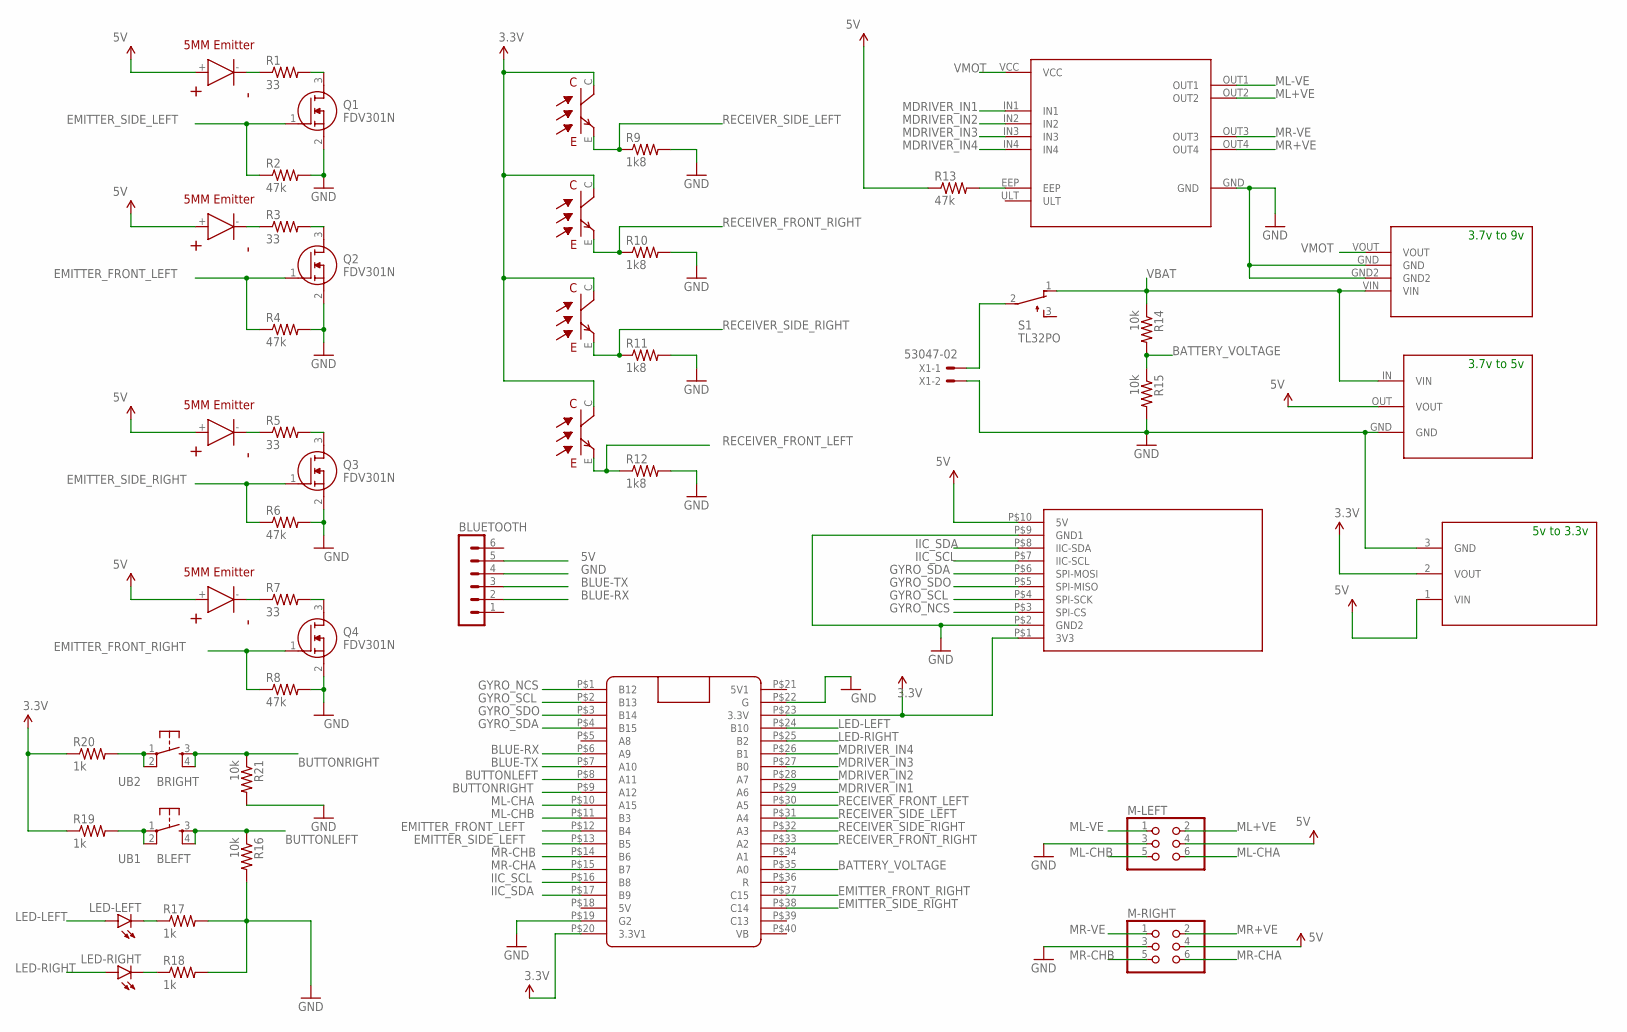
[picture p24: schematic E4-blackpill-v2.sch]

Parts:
BLUETOOTH: MA06-1
DET-FRONTLEFT: RECEIVER
DET-FRONTRIGHT: RECEIVER
DET-SIDELEFT: RECEIVER
DET-SIDERIGHT: RECEIVER
IR-FRONTLEFT: EMITTER
IR-FRONTRIGHT: EMITTER
IR-SIDELEFT: EMITTER
IR-SIDERIGHT: EMITTER
LED-LEFT: LEDSML0603; SML0603
LED-RIGHT: LEDSML0603; SML0603
M-LEFT: PINHD-2X3; 2X03
M-RIGHT: PINHD-2X3; 2X03
Q1, Q2, Q3, Q4: FDV301N; SOT96P237X111-3N
R1, R3, R5, R7: 33; 1206
R2, R4, R6, R8, R13: 47k; 0603-RES
R9, R10, R11, R12: 1k8; 0603-RES
R14, R15, R16, R21: 10k; 0603-RES
R17, R18, R19, R20: 1k; 0603-RES
S1: TL32PO; TL3XPO
U$1: E4_SPI-IIC
U$3: DRV8833
U$4: BUCK3TO9BUCK3TO9-HORIZONTAL; BUCK3TO9-HORIZONTAL
U$5: BUCK3TO5; BUCK3TO5-H
U$7: BLACK_PILL
U$8: 3V3-CONV3V3CONV; 6410-03
UB1: BLEFT; TACTILE-PTH
UB2: BRIGHT; TACTILE-PTH
X1: 53047-02

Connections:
3.3V: DET-FRONTLEFT.C, DET-FRONTRIGHT.C, DET-SIDELEFT.C, DET-SIDERIGHT.C, R19.1, R20.1, U$1.P$1 (3V3), U$7.P$20 (3.3V1), U$7.P$23 (3.3V), U$8.2 (VOUT)
5V: BLUETOOTH.5, IR-FRONTLEFT.+, IR-FRONTRIGHT.+, IR-SIDELEFT.+, IR-SIDERIGHT.+, M-LEFT.4, M-RIGHT.4, R13.1, U$1.P$10 (5V), U$5.OUT (VOUT), U$8.1 (VIN)
5V1: U$7.P$21 (5V1)
BATTERY_VOLTAGE: R14.2, R15.1, U$7.P$35 (A0)
BLUE-RX: BLUETOOTH.2, U$7.P$6 (A9)
BLUE-TX: BLUETOOTH.3, U$7.P$7 (A10)
BUTTONLEFT: R16.1, U$7.P$8 (A11), UB1.3, UB1.4
BUTTONRIGHT: R21.1, U$7.P$9 (A12), UB2.3, UB2.4
EMITTER_FRONT_LEFT: Q2.1 (G), R4.1, U$7.P$12 (B4)
EMITTER_FRONT_RIGHT: Q4.1 (G), R8.1, U$7.P$37 (C15)
EMITTER_SIDE_LEFT: Q1.1 (G), R2.1, U$7.P$13 (B5)
EMITTER_SIDE_RIGHT: Q3.1 (G), R6.1, U$7.P$38 (C14)
GND: BLUETOOTH.4, M-LEFT.3, M-RIGHT.3, Q1.2 (S), Q2.2 (S), Q3.2 (S), Q4.2 (S), R2.2, R4.2, R6.2, R8.2, R9.2, R10.2, R11.2, R12.2, R15.2, R16.2, R17.2, R18.2, R21.2, U$1.P$2 (GND2), U$1.P$9 (GND1), U$3.GND, U$4.GND, U$4.GND2, U$5.GND, U$7.P$19 (G2), U$7.P$22 (G), U$8.3 (GND), X1.2
GYRO_NCS: U$1.P$3 (SPI-CS), U$7.P$1 (B12)
GYRO_SCL: U$1.P$4 (SPI-SCK), U$7.P$2 (B13)
GYRO_SDA: U$1.P$6 (SPI-MOSI), U$7.P$4 (B15)
GYRO_SDO: U$1.P$5 (SPI-MISO), U$7.P$3 (B14)
IIC_SCL: U$1.P$7 (IIC-SCL), U$7.P$16 (B8)
IIC_SDA: U$1.P$8 (IIC-SDA), U$7.P$17 (B9)
LED-LEFT: LED-LEFT.A, U$7.P$24 (B10)
LED-RIGHT: LED-RIGHT.A, U$7.P$25 (B2)
MDRIVER_IN1: U$3.IN1, U$7.P$29 (A6)
MDRIVER_IN2: U$3.IN2, U$7.P$28 (A7)
MDRIVER_IN3: U$3.IN3, U$7.P$27 (B0)
MDRIVER_IN4: U$3.IN4, U$7.P$26 (B1)
ML+VE: M-LEFT.2, U$3.OUT2
ML-CHA: M-LEFT.6, U$7.P$10 (A15)
ML-CHB: M-LEFT.5, U$7.P$11 (B3)
ML-VE: M-LEFT.1, U$3.OUT1
MR+VE: M-RIGHT.2, U$3.OUT4
MR-CHA: M-RIGHT.6, U$7.P$15 (B7)
MR-CHB: M-RIGHT.5, U$7.P$14 (B6)
MR-VE: M-RIGHT.1, U$3.OUT3
unnamed: IR-FRONTRIGHT.-, R7.1
unnamed: Q1.3 (D), R1.2
unnamed: IR-SIDELEFT.-, R1.1
unnamed: IR-FRONTLEFT.-, R3.1
unnamed: Q2.3 (D), R3.2
unnamed: Q4.3 (D), R7.2
unnamed: IR-SIDERIGHT.-, R5.1
unnamed: Q3.3 (D), R5.2
unnamed: R13.2, U$3.EEP
unnamed: LED-RIGHT.C, R18.1
unnamed: LED-LEFT.C, R17.1
unnamed: R19.2, UB1.1, UB1.2
unnamed: R20.2, UB2.1, UB2.2
unnamed: S1.2, X1.1
RECEIVER_FRONT_LEFT: DET-FRONTLEFT.E, R12.1, U$7.P$30 (A5)
RECEIVER_FRONT_RIGHT: DET-FRONTRIGHT.E, R10.1, U$7.P$33 (A2)
RECEIVER_SIDE_LEFT: DET-SIDELEFT.E, R9.1, U$7.P$31 (A4)
RECEIVER_SIDE_RIGHT: DET-SIDERIGHT.E, R11.1, U$7.P$32 (A3)
VBAT: R14.1, S1.1 (O), U$4.VIN, U$5.IN (VIN)
VMOT: U$3.VCC, U$4.VOUT

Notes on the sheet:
3.7v to 9v
3.7v to 5v
5v to 3.3v

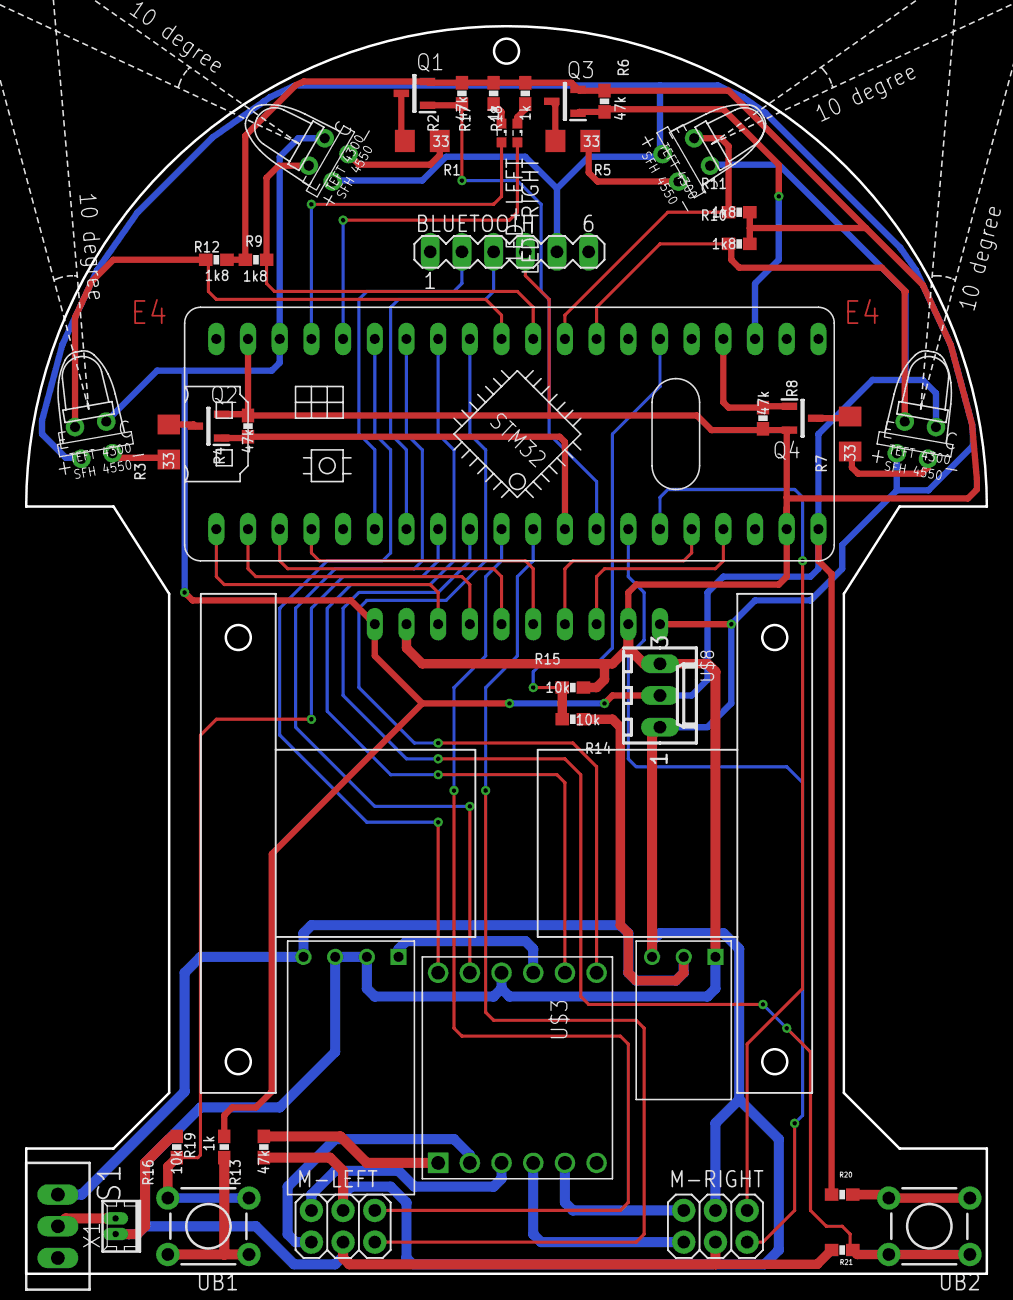
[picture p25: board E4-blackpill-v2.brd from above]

Board: 2 copper layers, 77.0 x 100.0 mm, 48 parts (0 on the bottom side), 52 nets.

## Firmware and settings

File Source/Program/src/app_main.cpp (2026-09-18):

#include <config.h>
#include "app_main.h"
#include "version.h"   // FW_VERSION / FW_BUILD
#include "ssd1306.h"
#include "mpu9250.h"
#include "IRS.h"
#include "PWM.h"
#include "encoders.h"
#include "maze.h"        // Phase 1: ported flood-fill maze solver
#include "native.h"      // time-weighted route planner (diagonal lattice)
#include "profile.h"     // Phase 1: ported trapezoidal motion profiles
#include "report.h"      // Phase 1: UART maze/telemetry reporting
#include "bluetooth.h"   // HM-10/HM-18 baud sweep + AT utility
#include "control.h"     // Phase 2: 1 kHz motion control loop
#include "odometry.h"    // Phase 2: encoder odometry
#include "motors_ctrl.h" // Phase 2: FF + PD motor controller
#include "gyro.h"         // Phase 4: MPU-9250 yaw heading
#include "mouse_config.h" // maze/turn geometry + search tuning
#include "motion.h"      // Motion facade (persistent-run locomotion)
#include "mouse.h"       // Phase: search/solve brain (+ world stubs)
#include "bt_rx.h"       // interrupt-driven UART1 receive ring buffer
#include "eeprom.h"      // 24LC256 persistence driver (diagnostic)
#include "config_store.h" // versioned settings block (gyro scale + wall thresholds)
#include <string.h>
#include <stdlib.h>

// access to global variables in system code generated files
extern I2C_HandleTypeDef hi2c1;
extern SPI_HandleTypeDef hspi2;
extern UART_HandleTypeDef huart1;
extern ADC_HandleTypeDef hadc1;
extern TIM_HandleTypeDef htim2;
extern TIM_HandleTypeDef htim3;
extern TIM_HandleTypeDef htim4;

// globzl variables
char zz[30];
int16_t cntr = 500;
uint8_t button_held = 0;
int16_t accData[3], gyroData[3];
static uint8_t s_haveOled = 1;   // set from SSD1306_Init(); 0 => run headless (no OLED)

// Two-colour 128x64 SSD1306 on E4: rows 0..15 are YELLOW, rows 16..63 are
// BLUE, with a single non-displayed pixel line at the seam (~y16). Never let
// a text line straddle the seam or it falls in the dead row. Title -> yellow,
// list -> blue. Tune here if a different panel is fitted.
static const int OLED_TITLE_Y = 3;    // title baseline, inside the yellow band
static const int OLED_LIST_Y0 = 18;   // first list row, just below the seam (blue)
static const int OLED_ROW_H   = 12;   // line pitch in the blue band (3 rows: 18,30,42)

float xval,yval,zval;
int16_t xval_raw = 0;
int16_t yval_raw = 0;
int16_t zval_raw = 0;

uint32_t then = 0, now = 0;
uint32_t butthen = 0, butnow = 0;
uint16_t cntL = 0, cntR = 0;

// ===================== Menu / launcher =====================
// Two-button scroll & select: LEFT = next item, RIGHT = run highlighted.
// Also driveable over BT: '1'..'9' run item N, 'n'/'p' navigate, 'r'/space run.
typedef void (*menu_action_t)(void);

static void act_forward (void) { control_forward_move(180.0f, 180.0f, 0.0f, 1000.0f); }
// Both read the ONE turn table, so "Right 90" from the menu and the turn she
// makes while searching are the same turn. They were not before: this used to
// hardcode alpha 1000 while turn_params carried 2500.
static void run_arc_from_table(int idx) {
	const TurnParameters &p = turn_params[idx];
	control_arc_turn((float)p.speed, (float)p.entry_offset, p.angle,
	                 p.omega, p.alpha, (float)p.lead_out);
}
// THE APPROACH IS PART OF THE TURN. run_arc_from_table drives lead_in ==
// entry_offset, which starts the arc that many millimetres after she begins
// moving -- fine for "does this arc look right", useless for "does she come out
// of it in the lane". A tuning run has to start where the turn really starts:
// back against the wall, out through `cells` whole cells, and the arc beginning
// entry_offset BEFORE the centre of the cell it belongs to.
//
//   lead_in = BACK_WALL_TO_CENTER + cells * FULL_CELL - entry_offset
//
// So the approach follows entry_offset instead of being re-typed after every
// change to it, which is where the arithmetic errors come from. cells = 0 keeps
// the old behaviour for anything that wants a bare arc.
//
// HALF THESE TURNS ARE NOT ENTERED FROM A STRAIGHT. DS45, DS135 and DD90 all
// begin on the diagonal, where the pitch is 127.279 mm rather than 180 and
// there is no back wall to square up on -- she is placed on the diagonal line
// by hand. So the approach for those rows counts diagonal steps from where she
// stands, and the back-wall term does not appear:
//
//   diagonal:  lead_in = cells * DIAG_PITCH - entry_offset
//
// Which it is follows from the row, not from a switch anyone has to remember
// to set: a turn that leaves the diagonal is a turn that was already on it.
static bool row_enters_on_diagonal(int idx) {
	return idx == DS45L || idx == DS45R || idx == DS135L || idx == DS135R
	    || idx == DD90L || idx == DD90R;
}
static float arc_pitch(int idx) {
	return row_enters_on_diagonal(idx) ? plan::DIAG_PITCH : FULL_CELL;
}
static float arc_lead_in(int idx, int cells) {
	const TurnParameters &p = turn_params[idx];
	if (cells <= 0) return (float)p.entry_offset;
	const float base = row_enters_on_diagonal(idx) ? 0.0f : BACK_WALL_TO_CENTER;
	float d = base + (float)cells * arc_pitch(idx) - (float)p.entry_offset;
	return (d > 0.0f) ? d : 0.0f;
}
static void run_arc_tuned(int idx, int cells) {
	const TurnParameters &p = turn_params[idx];
	control_arc_turn((float)p.speed, arc_lead_in(idx, cells), p.angle,
	                 p.omega, p.alpha, (float)p.lead_out);
}
static void act_right90 (void) { run_arc_from_table(1); }   // SS90ER
static void act_left90  (void) { run_arc_from_table(0); }   // SS90EL
// Same divergence the 90s had: this used to hardcode omega 180 / alpha 1000
// while turn_IP180() used 360 / 3600, so "Spin 180" from the menu and the
// 180 she makes at a dead end were different spins.
static void act_spin180 (void) { control_spin(180.0f, OMEGA_SPIN_TURN, 0.0f, ALPHA_SPIN_TURN); }

static void act_recal_gyro(void) {
	SSD1306_Fill(SSD1306_COLOR_BLACK);
	SSD1306_GotoXY(0, 3);  SSD1306_Puts("Recal gyro",    &Font_7x10, SSD1306_COLOR_WHITE);
	SSD1306_GotoXY(0, 26); SSD1306_Puts("hold still...", &Font_7x10, SSD1306_COLOR_WHITE);
	SSD1306_UpdateScreen();
	control_recalibrate_gyro();   // ISR-safe bias re-cal
}
static void act_reset_pose(void) {
	control_pose_reset();
	report_write("RST\r\n");          // tell the app to re-centre
	control_stream_telemetry();
}
static void act_toggle_test(void) {
	control_set_test_mode(!control_test_mode());
	control_pose_reset();             // move the start immediately
	report_write("RST\r\n");
	control_stream_telemetry();
}
static void act_set_bt_57k(void) {
	// One-time: move the MCU<->module UART link to 57600 (module NVM persists).
	// Run with NO phone connected so the module is in AT command mode. The MCU
	// now boots at 57600 (usart.c), so on the first run the module is still at
	// its old baud; ensure_baud sweeps to find it, switches it, and settles here.
	bt_ensure_baud(57600);
	bt_rx_init();      // DeInit/Init during re-baud cleared the RXNE interrupt
	HAL_Delay(1800);   // hold the OLED result so it can be read
}

static void act_bt_provision(void) {
	// Bring-up for a NEW or replacement module, straight out of its bag: find
	// it at whatever baud it ships on, move it to 57600, name it MMOUSE, reset
	// so that name is what it advertises. Takes no input -- the name is fixed.
	//
	// Run with NO phone connected. The module only accepts AT commands while
	// no central is attached, so there is nothing listening over BT either:
	// the OLED is the whole interface for this one.
	bt_provision();
	bt_rx_init();      // re-baud cleared the RXNE interrupt
	HAL_Delay(2600);   // hold the result -- there are four lines to read
}

// Substrate self-test: prove the persistent-run + concurrent forward/rotation
// model makes a coordinated curve. Scripts fwd -> smooth right -> fwd via the
// Motion facade. (Temporary home on menu item 8 until the brain port lands.)
static void act_motion_test(void) {
	while (SWITCH_LEFT() || SWITCH_RIGHT()) { HAL_Delay(5); }  // wait for release
	HAL_Delay(800);                                            // hands-off settle
	report_write("motion test: fwd, smooth R, fwd\r\n");
	control_run_begin();                                       // closed loop live for the whole run
	motion.move(BACK_WALL_TO_CENTER, SEARCH_SPEED, SEARCH_TURN_SPEED, SEARCH_ACCELERATION);
	motion.set_position(HALF_CELL);
	motion.move(FULL_CELL, SEARCH_TURN_SPEED, SEARCH_TURN_SPEED, SEARCH_ACCELERATION);
	motion.set_target_velocity(SEARCH_TURN_SPEED);             // hold speed through the turn
	motion.turn(-90.0f, 170.0f, 0.0f, 1000.0f);                // rotation + forward together = curve
	motion.move(FULL_CELL, SEARCH_TURN_SPEED, 0.0f, SEARCH_ACCELERATION);
	control_run_end();
	report_printf("motion test done: gyro_a=%d d=%d\r\n",
	              (int)gyro.angle(), (int)odometry.robot_distance());
}

// --- Chained-zigzag test -------------------------------------------------
//
// SETTLES AN ARGUMENT between the route planner and the firmware.
//
// A chainable 90 is a quarter circle of radius 90 mm -- HALF A CELL. It starts
// at the midpoint of the wall she enters by and ends at the midpoint of the
// wall she leaves by, so it begins and ends exactly on a cell boundary, on the
// corridor centreline, and the next one can start where the last finished with
// nothing in between. 90 mm forward, 90 mm sideways. That is the whole
// requirement, and it is geometry, not tuning.
//
// She does not do that. R = v / omega = 300 / (170 deg/s in rad) = 101 mm is
// the number usually quoted, and it is already too wide -- but it is also not
// the displacement, because alpha is finite and omega ramps. Integrating the
// actual trapezoidal profile at v 300, omega 170, alpha 2500 gives 111.5 mm
// forward and 111.5 mm sideways: 21.5 mm wider than a turn that fits. Two of
// them one cell apart need 223 mm and have 180.
//
// So the planner refuses and emits stop-and-spin, and it is right about its own
// model.
//
// turn_smooth() never refuses. After a turn it relabels the frame to
// SENSING_POSITION + exit_offset (170 + 30 = 200), and the next turn waits on
// `while (position < FULL_CELL + HALF_CELL - entry_offset)` = 170, which is
// already false. So the wait loop does not run and the second arc begins the
// instant the first ends: the two overlap and she cuts the corner rather than
// returning to the centreline between them.
//
// Which is correct is a question about the floor, not the code. This drives
// the case deliberately: N alternating 90s in consecutive cells with no
// straight between, finishing stopped at a cell centre so the offset can be
// measured against a wall. Mode 1 drives the same path as stop-and-spin for
// comparison -- that is what the planner currently believes she must do.
//
// Needs a 3x3 open section for the default 3 turns: from the start cell she
// ends two cells across and two up.
//
// WHICH ROW. SS90E and SS90 are separate rows precisely so they can be
// different turns, and only the speed-run row has to chain. Searching, she
// stops and senses every cell and wall-following re-centres her, so a wide arc
// costs nothing but a little scrub -- SS90E is tuned and should stay as it is.
// SS90 is the one a fast run strings together, so that is what this drives by
// default, with SS90E available as a comparison rather than as the subject.
//
//   ZIG,turns,mode,first,row   over BT   mode 0 = chained arcs, 1 = spins
//                                        first 1 = right, 0 = left
//                                        row  1 = SS90 (speed run), 0 = SS90E
static int s_zig_turns = 3;
static int s_zig_mode  = 0;
static int s_zig_right = 1;
static int s_zig_row   = 1;    // the speed-run turn: the one that has to chain

static void act_zigzag_test(void) {
	while (SWITCH_LEFT() || SWITCH_RIGHT()) { HAL_Delay(5); }   // release the select press
	HAL_Delay(800);                                             // hands-off settle
	// The row's OWN speed, not SEARCH_SPEED. A speed-run turn tuned at 500 mm/s
	// tells you nothing if the test approaches it at 300, and both modes have to
	// use the same number or the comparison is between two different runs.
	const TurnParameters &row0 = turn_params[s_zig_row ? SS90L : SS90EL];
	const float v = (row0.speed > 0) ? (float)row0.speed : SEARCH_TURN_SPEED;

	report_printf("ZIG,start turns=%d mode=%s first=%c row=%s v=%d\r\n", s_zig_turns,
	              s_zig_mode ? "spin" : "arc", s_zig_right ? 'R' : 'L',
	              s_zig_row ? "SS90" : "SS90E", (int)v);
	control_run_begin();

	// Out of the start cell to its centre, exactly as search_to() begins.
	motion.move(BACK_WALL_TO_CENTER, v, v, SEARCH_ACCELERATION);
	motion.set_position(HALF_CELL);

	int right = s_zig_right;
	for (int i = 0; i < s_zig_turns; i++) {
		const int id = s_zig_row ? (right ? SS90R : SS90L) : (right ? SS90ER : SS90EL);
		const TurnParameters &p = turn_params[id];
		if (s_zig_mode) {
			// Reference: coast to the cell centre, stop, spin, move off again --
			// the same shape turn_back() uses.
			float remaining = (FULL_CELL + HALF_CELL) - motion.position();
			if (remaining > 0.0f) motion.move(remaining, v, 0.0f, SEARCH_ACCELERATION);
			motion.reset_drive_system();
			control_spin(right ? -90.0f : 90.0f, OMEGA_SPIN_TURN, 0.0f, ALPHA_SPIN_TURN);
			motion.move(SENSING_POSITION - HALF_CELL, v, v, SEARCH_ACCELERATION);
			motion.set_position(SENSING_POSITION);
		} else {
			// The case under test. On the first turn the wait loop runs; on every
			// one after it the frame relabel has already put her past the turn
			// point, so the arc fires immediately. That is the chaining.
			motion.set_target_velocity(v);
			float turn_point = FULL_CELL + HALF_CELL - (float)p.entry_offset;
			while (motion.position() < turn_point) { motion.stream_periodic(); }
			motion.turn(p.angle, p.omega, 0.0f, p.alpha);
			motion.set_position(SENSING_POSITION + (float)p.exit_offset);
		}
		report_printf("ZIG,turn %d %c gyro=%d pos=%d\r\n", i + 1, right ? 'R' : 'L',
		              (int)gyro.angle(), (int)motion.position());
		right = !right;
	}

	// Coast to the centre of the cell she finished in, so the stop is a datum
	// you can hold a rule against rather than a place she happened to halt.
	float remaining = (FULL_CELL + HALF_CELL) - motion.position();
	if (remaining > 0.0f) motion.move(remaining, v, 0.0f, SEARCH_ACCELERATION);
	control_run_end();

	// Alternating 90s cancel in pairs, so the net is one turn's worth if the
	// count is odd and nothing if it is even.
	int expect = (s_zig_turns & 1) ? (s_zig_right ? -90 : 90) : 0;
	report_printf("ZIG,done row=%s gyro=%d expect=%d err=%d dist=%d\r\n",
	              s_zig_row ? "SS90" : "SS90E",
	              (int)gyro.angle(), expect, (int)gyro.angle() - expect,
	              (int)odometry.robot_distance());
}
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
void app_main()
{
	// initialise modules
	LED_ALL_ON();				// All LEDs lit
	MPU_Initialise();			// Communication for MPU and initial setting of Gyro
	s_haveOled = SSD1306_Init();   // 0 if no OLED on the bus (bare test board)
	Motor_Initialize();
	Motor_StopPWM();
	Encoder_Initialize();

	report_write("E4 boot\r\n");
	report_printf("VER,%s,%s\r\n", FW_VERSION, FW_BUILD);

	// Settings block: gyro scale (and later the wall thresholds) come from the
	// EEPROM if one is fitted and holds a valid block. No chip is not an error -
	// the compiled defaults stand and nothing persists.
	config_store_begin();

	{
		char vln[24];
		SSD1306_GotoXY (0, 0);
		snprintf(vln, sizeof(vln), "E4  v%s", FW_VERSION);
		SSD1306_Puts (vln, &Font_7x10, SSD1306_COLOR_WHITE);
		SSD1306_GotoXY (0, 16);
		SSD1306_Puts ("(c) James Clarke", &Font_7x10, SSD1306_COLOR_WHITE);
		SSD1306_GotoXY (0, 36);
		SSD1306_Puts (__DATE__, &Font_7x10, SSD1306_COLOR_WHITE);
		SSD1306_GotoXY (0, 50);
		SSD1306_Puts (__TIME__, &Font_7x10, SSD1306_COLOR_WHITE);
		SSD1306_UpdateScreen(); //display
	}

	HAL_Delay(1600);

	SSD1306_Clear();
	SSD1306_GotoXY (0,0);


	// --- Phase 2/4: bring up the 1 kHz motion control loop (+ gyro) ---
	// control_begin() calibrates the gyro (hold still ~0.6 s), then arms the
	// SysTick control ISR in IDLE: loop + odometry + gyro live, motors OFF.
	SSD1306_Clear();
	SSD1306_GotoXY (0, 0);
	SSD1306_Puts ("Gyro calibrating", &Font_7x10, SSD1306_COLOR_WHITE);
	SSD1306_GotoXY (0, 26);
	SSD1306_Puts ("hold still...", &Font_7x10, SSD1306_COLOR_WHITE);
	SSD1306_UpdateScreen();
	control_begin();
	bt_rx_init();          // interrupt-driven BT receive (menu + maze injection)
	SSD1306_Clear();

	// NO TOY MAZE AT BOOT. This used to seed a two-cell bring-up maze into the
	// virtual sensor and move the goal to (1,1) to match it, which was right
	// when there were no sensor housings and no way to inject a real maze.
	//
	// It outlived that by months and became a trap. It ran on EVERY power-up,
	// so any goal you had set was silently replaced, and a Plan route or a Sim
	// explore against it succeeded -- against the wrong maze, with the wrong
	// goal, reporting a perfectly healthy-looking two-cell solution. A failure
	// that looks like a success is worse than one that looks like a failure.
	//
	// She now boots with maze.h's own m_goal{7, 7} and an OPEN arena as ground
	// truth: no interior walls, perimeter sealed. The perimeter is not optional
	// -- truth is not constructed with one, so leaving it alone would hand the
	// virtual sensor a world with no edges and the first simulated run would
	// drive her off it. Open-and-sealed is the honest empty state: it says
	// nothing about the maze while still being a maze.
	//
	// Send her a file, or explore one.
	truth_clear();

	int level = 0, mode = 0, cat = 0, sel = 0, top = 0;
	uint8_t left_prev = 0, right_prev = 0;
	uint32_t stream_then = 0;
	long jog_ref = (long)MENU_JOG_DIR * ((long)odometry.total_left() + odometry.total_right());

	menu_render(level, mode, cat, sel, top);
	report_write("E4 ready. Wheels scroll; RIGHT=enter/run, LEFT=back. BT: <key> runs an action, n/p scroll, r enter, < back\r\n");

	while (1)
	{
		// keep the controller's battery estimate fresh (blocking ADC: main loop only)
		control_update_battery(Battery_GetVoltage());

		// idle heartbeat only: a slow 1 Hz pose so the app shows she is there.
		if (HAL_GetTick() - stream_then >= 1000) {
			stream_then = HAL_GetTick();
			control_stream_telemetry();
		}

		bool dirty   = false;
		int  run_idx = -1;                                   // MENU index to run, or -1
		int  count   = (level == 0) ? NUM_MODE : (level == 1) ? (int)MODE[mode].n : (int)CAT[cat].n;

		// --- buttons: RIGHT = enter/run, LEFT = back ---
		uint8_t l = SWITCH_LEFT();
		uint8_t r = SWITCH_RIGHT();
		if (r && !right_prev) {
			if      (level == 0) { mode = sel; level = 1; sel = 0; top = 0; dirty = true; }         // enter mode
			else if (level == 1) { cat = MODE[mode].cats[sel]; level = 2; sel = 0; top = 0; dirty = true; }  // enter category
			else                 { run_idx = CAT[cat].items[sel]; }                              // run item
		}
		if (l && !left_prev) {
			if      (level == 2) { level = 1; sel = cat_pos_in_mode(mode, cat); top = 0; dirty = true; }     // back to categories
			else if (level == 1) { level = 0; sel = mode; top = 0; dirty = true; }                           // back to modes
		}
		left_prev  = l;
		right_prev = r;
		count = (level == 0) ? NUM_MODE : (level == 1) ? (int)MODE[mode].n : (int)CAT[cat].n;    // level may have changed

		// --- wheel jog: spin/roll the wheels to scroll the current view ---
		long jog = (long)MENU_JOG_DIR * ((long)odometry.total_left() + odometry.total_right());
		while (jog - jog_ref >=  MENU_JOG_COUNTS) { if (sel < count - 1) sel++; jog_ref += MENU_JOG_COUNTS; dirty = true; }
		while (jog - jog_ref <= -MENU_JOG_COUNTS) { if (sel > 0) sel--; jog_ref -= MENU_JOG_COUNTS; dirty = true; }
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

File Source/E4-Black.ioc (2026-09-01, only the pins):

Mcu.UserName=STM32F411CEUx
PA0-WKUP.Signal=ADCx_IN0
PA10.Signal=USART1_RX
PA11.GPIO_Label=BUTTON_LEFT
PA11.Signal=GPIO_Input
PA12.GPIO_Label=BUTTON_RIGHT
PA12.Signal=GPIO_Input
PA13.Signal=SYS_JTMS-SWDIO
PA14.Signal=SYS_JTCK-SWCLK
PA15.Signal=S_TIM2_CH1_ETR
PA2.Signal=ADCx_IN2
PA3.Signal=ADCx_IN3
PA4.Signal=ADCx_IN4
PA5.Signal=ADCx_IN5
PA6.Signal=S_TIM3_CH1
PA7.Signal=S_TIM3_CH2
PA9.Signal=USART1_TX
PB0.Signal=S_TIM3_CH3
PB1.Signal=S_TIM3_CH4
PB10.GPIO_Label=LED_LEFT
PB10.Signal=GPIO_Output
PB12.Signal=GPIO_Output
PB13.Signal=SPI2_SCK
PB14.Signal=SPI2_MISO
PB15.Signal=SPI2_MOSI
PB2.GPIO_Label=LED_RIGHT
PB2.Signal=GPIO_Output
PB3.Signal=S_TIM2_CH2
PB4.GPIO_Label=IR_FRONT_LEFT
PB4.Signal=GPIO_Output
PB5.GPIO_Label=IR_SIDE_LEFT
PB5.Signal=GPIO_Output
PB6.Signal=S_TIM4_CH1
PB7.Signal=S_TIM4_CH2
PB8.Signal=I2C1_SCL
PB9.Signal=I2C1_SDA
PC13-ANTI_TAMP.GPIO_Label=LED-ON
PC13-ANTI_TAMP.Signal=GPIO_Output
PC14-OSC32_IN.GPIO_Label=IR_SIDE_RIGHT
PC14-OSC32_IN.Signal=GPIO_Output
PC15-OSC32_OUT.GPIO_Label=IR_FRONT_RIGHT
PC15-OSC32_OUT.Signal=GPIO_Output

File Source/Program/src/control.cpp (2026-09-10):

/*
 * control.cpp  -- see control.h
 */
#include "control.h"
#include "config.h"        // SWITCH_LEFT/RIGHT macros, HAL_Delay
#include "motion_config.h"
#include "odometry.h"
#include "gyro.h"
#include "report.h"
#include "motors_ctrl.h"
#include "profile.h"       // extern Profile forward, rotation
#include "IRS.h"          // Battery_GetVoltage for the low-battery guard; Irs_Tick
#include <math.h>

enum CtrlMode { CTRL_IDLE = 0, CTRL_OPEN_LOOP, CTRL_CLOSED_LOOP };

static volatile CtrlMode s_mode        = CTRL_IDLE;
static volatile bool     s_enabled     = false;
static volatile float    s_open_left_v = 0.0f;
static volatile float    s_open_right_v= 0.0f;

// Dead-reckoned pose for the maze app. Absolute heading integrated separately
// from gyro.angle() so the per-move gyro.reset_angle() calls don't disturb it.
static volatile float s_pose_x = 90.0f, s_pose_y = 90.0f, s_pose_heading = 0.0f;

// Runtime bench test-mode: when true, control_pose_reset() applies the
// POSE_TEST_*_OFFSET so a move can be run from an on-maze spot. Default OFF
// (real column-0 start). Toggled from the menu; never persisted.
static bool s_test_mode = false;

// --- Low-battery cutoff state (thresholds live in motion_config.h) ----------
static uint32_t s_batt_low_since = 0;   // tick the pack first dropped low (0 = not low)
static bool     s_batt_tripped   = false;
bool control_batt_tripped() { return s_batt_tripped; }

// ---------------------------------------------------------------------------
// The 1 kHz control ISR. Keep it short and non-blocking. No HAL_Delay, no
// blocking ADC (battery is fed in from the main loop).
// ---------------------------------------------------------------------------
extern "C" void control_isr(void) {
  // Background wall sampler: one state per tick, a full ambient-subtracted set
  // every 5 ms, no busy-wait (see IRS.h). Ticked ahead of the s_enabled gate so
  // it keeps running while the control loop is parked -- the IR monitor and the
  // gyro re-cal both hold s_enabled low, and neither touches the ADC. It is a
  // no-op unless armed, and stands aside whenever thread context owns the ADC,
  // so the main-loop battery read (the low-battery cutoff) always wins.
  Irs_Tick();

  if (!s_enabled) {
    return;
  }
  odometry.update();                       // always keep localisation live
  gyro.update();                           // integrate yaw heading (drives rotation control)
  // Dead-reckon absolute pose (mm) for the maze app.
  s_pose_heading += gyro.rate_change();
  {
    float ds = odometry.robot_fwd_change();
    float th = DEG2RAD(s_pose_heading);
    s_pose_x += -ds * sinf(th);
    s_pose_y +=  ds * cosf(th);
  }
  if (s_batt_tripped) {
    motors.stop();                         // low-battery lockout: motors held off
  } else
  switch (s_mode) {
    case CTRL_IDLE:
      break;                               // motors already stopped
    case CTRL_OPEN_LOOP:
      motors.set_left_motor_volts(s_open_left_v);
      motors.set_right_motor_volts(s_open_right_v);
      break;
    case CTRL_CLOSED_LOOP:
      forward.update();
      rotation.update();
      motors.update_controllers(forward.speed(), rotation.speed(), 0.0f);
      break;
  }
}

void control_begin() {
  odometry.begin();
  gyro.begin();          // ~600 ms zero-rate calibration -- hold still
  motors.begin();
  forward.reset();
  rotation.reset();
  control_pose_reset();
  s_mode = CTRL_IDLE;
  s_enabled = true;        // ISR live from here, but IDLE keeps motors off
  report_write("RST\r\n");  // tell the maze app to start a fresh view
}

void control_set_idle() {
  s_mode = CTRL_IDLE;
  motors.disable_controllers();
  motors.stop();
}

// --- Persistent run mode for the maze solver (motion.cpp / mouse.cpp) -------
// Unlike the one-shot control_forward_move / _spin / _arc_turn calls, a "run"
// keeps the closed loop engaged across many profile segments so the mouse
// brain can start moves/turns and react at trigger points while the ISR ticks
// the forward + rotation profiles and the motor controller.

void control_drive_reset() {
  // Clean slate ready to move WITHOUT ending the run: profiles + odometry
  // zeroed and controllers re-armed, but the closed loop stays engaged.
  // Heading (gyro) is left running so it is continuous across the whole run.
  motors.stop();
  odometry.reset();
  forward.reset();
  rotation.reset();
  motors.reset_controllers();
  motors.enable_controllers();
  s_mode = CTRL_CLOSED_LOOP;
}

void control_run_begin() {
  // Enter a run from idle: zero the heading reference, then drive-reset.
  gyro.reset_angle();
  control_drive_reset();
}

void control_run_end() {
  s_mode = CTRL_IDLE;
  motors.disable_controllers();
  motors.stop();
}

void control_update_battery(float v) {
  motors.set_battery_voltage(v);

  // Low-battery cutoff. Ignore implausible readings (no pack / USB bench
  // power): a cell that isn't there can't be over-discharged, and a ~0 V sense
  // line must never park the motors.
  if (v < BATT_VALID_VOLTS) { s_batt_low_since = 0; return; }

  if (v < BATT_CUTOFF_VOLTS) {
    uint32_t now = HAL_GetTick();
    if (s_batt_low_since == 0) {
      s_batt_low_since = now ? now : 1;                 // 0 is the "clear" sentinel
    } else if (!s_batt_tripped && (now - s_batt_low_since) >= BATT_CUTOFF_MS) {
      s_batt_tripped = true;
      control_run_end();                                // motors off, controllers disabled
      int iv = (int)v, fv = (int)(v * 100) % 100; if (fv < 0) fv = -fv;
      report_printf("ACT,lowbatt\r\n");
      report_printf("STATE,LOWBATT %d.%02dV\r\n", iv, fv);
    }
  } else if (v >= BATT_RECOVER_VOLTS) {
    s_batt_low_since = 0;
    s_batt_tripped   = false;                           // re-arm once the pack recovers
  } else {
    s_batt_low_since = 0;                               // 3.30-3.45 band: not sustained-low now
  }
}

void control_open_loop_pulse(float left_volts, float right_volts, uint32_t ms) {
  if (control_batt_tripped()) return;   // low-battery lockout
  motors.reset_controllers();
  odometry.reset();
  s_open_left_v  = left_volts;   // set volts BEFORE switching mode
  s_open_right_v = right_volts;
  s_mode = CTRL_OPEN_LOOP;
  HAL_Delay(ms);
  s_mode = CTRL_IDLE;
  motors.stop();
}
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

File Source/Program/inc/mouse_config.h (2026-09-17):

/*
 * mouse_config.h  --  maze/motion geometry and search tuning for E4.
 *
 * Ported from mazerunner-core's robot config (full-size 180 mm classic maze,
 * matching e4-maze.html), adapted to E4's drivetrain and the turn geometry we
 * bench-tuned. C++-only (const/constexpr with internal linkage, header-safe).
 */
#ifndef MOUSE_CONFIG_H
#define MOUSE_CONFIG_H

#include "maze.h"   // Location, Heading, Direction, TurnParameters users

// --- Goal room ("one entrance to the centre" rule) -------------------------
// The classic full-size goal is a 2x2 room; GOAL_ROOM_X0/Y0 is its SW corner.
// Once the mouse enters it, the whole room is asserted (see Mouse::assert_goal_room).
const int GOAL_ROOM_X0 = 7;
const int GOAL_ROOM_Y0 = 7;

// --- Cell geometry (full-size classic maze) --------------------------------
const float FULL_CELL = 180.0f;
const float HALF_CELL = 90.0f;

// Distance from the backed-against-the-back-wall start to the first cell
// centre. E4: the axle sits 41 mm from the back boundary, centre is at 90 mm.
const float BACK_WALL_TO_CENTER = 49.0f;

// Position within a cell (measured from its back boundary) at which the mouse
// reads the walls of the cell it is about to enter, and re-syncs each step.
const float SENSING_POSITION = 170.0f;

// --- Search speeds / acceleration (mm/s, mm/s/s) ---------------------------
const float SEARCH_SPEED        = 300.0f;
const float SEARCH_ACCELERATION = 2000.0f;
const float SEARCH_TURN_SPEED   = 300.0f;   // forward speed held through a smooth turn

// --- Simulator playback ----------------------------------------------------
// The simulator animates at the speed the motion model says she would really
// move, so what you watch is the prediction rather than a fixed frame count.
// SIM_RATE only scales the WATCHING: 2 makes it twice as quick to sit through,
// and the reported time is unaffected, because that comes from the model and
// not from the clock on the wall.
extern float SIM_RATE;

// --- Wall follower ---------------------------------------------------------
// How many cells before she admits the hand she is following does not reach
// the goal.
//
// On a WALL-FOLLOWER course this never trips: those courses are built with a
// wall connected to the centre, so the hand always gets there. On a MAZE-
// SOLVER maze it always trips, because those are built with the inside
// disconnected from the outside on purpose. Same code, two events, and the
// limit is what lets the second one end in a sentence instead of a walk that
// never finishes. 512 is four times the cells in the arena.
const int FOLLOW_STEP_LIMIT = 512;

// --- Fast-run speeds (mm/s, mm/s/s) ---------------------------------------
// The SEARCH values above are what she explores at, and they are bounded by
// something real: she reads walls and decides where to go once per cell, so
// how fast she may search is a sensor question settled at the bench. The fast
// run has no such limit -- the map is already known -- and these are its
// numbers.
//
// Keeping them apart is what gives the planner a question to answer. While
// v_max equalled the turn speed she went as fast down a straight as round a
// corner, so SHORTEST and QUICKEST returned the same route to the millisecond
// and there was no "quickest" to find. Only when a straight can outrun a turn
// does a longer, straighter line start to beat a shorter, twistier one.
//
// RUN_DIAG_SPEED is deliberately lower. The diagonal corridor is 110.3 mm
// between posts against 168 mm down a cell, which leaves her about 14 mm a
// side with the plate and housings fitted rather than 43. She threads it; she
// does not charge it.
//
// NOT const: like the turn table and the spin dynamics these are measured, not
// chosen. Defined once in mouse.cpp, settable over BT with SPD, persisted in
// the EEPROM config block. The values there are the fallback.
//
// Nothing drives on these yet -- act_speed_run is still a stub. Today they are
// read by the planner alone, which is why a wrong value here costs a wrong
// estimate and not a wrecked mouse.
extern float RUN_SPEED;
extern float RUN_ACCELERATION;
extern float RUN_DIAG_SPEED;
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

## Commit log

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2026-09-08 Firmware: batched IR read, ADC timing, build version, menu tools
    - IRS: two-phase batched wall read (Irs_Read_Diff_All) - one dark phase
    then a per-emitter lit phase; named settle constants IR_LIT_SETTLE_COUNT
    (~50us) and IR_DARK_SETTLE_COUNT, replacing the old fixed DELAY_COUNT
    - ADC: raise IR-channel sample time 3 -> 28 cycles for the 1.8k detector load
    - version.h: FW_VERSION + auto build stamp; shown on the OLED boot splash,
    streamed as "VER,<ver>,<build>" at boot, and via a new Firmware-ver action
    - menu: add "Emitter hold" (steady-emitter camera aid) and "Firmware ver"
    under Diagnostics
    - robot_sensors: confirmed detector map (SL/SR = side walls, FL/FR = front)
    - assorted contr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
    [IRS.c, app_main.cpp, bluetooth.cpp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]
2026-09-08 App: sensor labels, IDENT pulse, firmware-version chip
    - correct the sensor markers (outer FL/FR = forward, inner SL/SR = sides)
    - add per-sensor IDENT pulse riding the EMIT stream for camera verification
    - parse the VER report and show a firmware-version chip in the header
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2026-09-09 Docs: mark Turn tuning built in the menu map (Ch6)
    Turn tuning flips Stub -> Built (live BT tuner + gyro scale calibrated);
    tally 21 built / 4 stubbed; roadmap item marked shipped.
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2026-09-11 Feature/gyro scale runtime (#8)
    * Gyro scale: runtime variable, on-floor calibration, EEPROM persistence
    GYRO_SCALE was a compile-time const, so every recalibration meant an
    edit-compile-flash cycle. It is a property of the individual MPU-9250 die
    (sensitivity tolerance is a few percent) and it shifts with temperature, so it
    belongs in the mouse, not in the source. It also has to be re-earned whenever
    the daughter board is swapped, which is imminent.
    CORRECTION TO THE OBVIOUS DESIGN, and why this is not fully automatic: the spin
    is gyro-CLOSED-LOOP. The controller turns until the gyro says it has reached the
    target, so gyro.angle() comes back at the commanded angle every time, by
    construct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
    [app_main.cpp, config.c, config_store.cpp]
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2026-09-11 BT provision: one-press bring-up for a replacement module
    A new module out of its bag is at 9600 with a name like HMSoft, which means it
    cannot talk to her at all until someone sits down with a USB-serial adapter.
    This makes it one menu press.
    Diagnostics > BT provision (key B) sweeps to find the module at whatever baud
    it ships on, moves it to 57600, names it MMOUSE and resets so that name is
    what it actually advertises. It takes no input: the name is a fixed constant,
    because it never needs to be anything else - the app filters on the FFE0
    service, not the name, so the name exists only so a human can pick her out of
    a scan list.
    Two thirds of this already existed. bt_baud_sweep() and bt_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
    [app_main.cpp, bluetooth.cpp]
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2026-09-13 Threshold cal: third capture, the corridor (0.12)
    Two captures do not constrain the front channel, and the gap is not
    academic.
    In a corridor the forward pair clips the SIDE walls through its 15
    degree splay, so the front sum reads far above its open-floor figure
    with no front wall present at all - on the old build, ~341 against a
    floor of ~22. A threshold taken as the midpoint of dead-end and open
    floor can land below that, and she then reports a front wall in every
    corridor she drives into. That presents as a maze-solving fault, which
    is the worst kind of sensor bug to own.
    So there is now a third state: CORRIDOR (side walls, no front wall),
    captured with RIGHT or 'C'.
    The rule is now s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
    [app_main.cpp]
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2026-09-13 Show what is running, on both displays (0.13)
    Two gaps James found, and the second is the one that would bite at a
    competition.
    The OLED did not follow a BT-started action. A shortcut key sets run_idx
    and runs the action directly, without walking the menu, so the display
    carried on showing whichever page it had been left on while she did
    something else entirely. Now any run - key or button - first locates the
    item in the MODE/CATEGORY/ITEM tree, points the menu at it, and puts
    "Running <name>" up. Actions with their own display overwrite that at
    once; the ones without leave the name showing, which is what you want.
    On exit the normal redraw leaves the cursor on the item just run, so the
    mou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
    [app_main.cpp]
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2026-09-13 One turn, tunable live, saved to EEPROM (0.14)
    The same 90 degree turn was described in three places and they had
    already drifted: the menu move hardcoded alpha 1000 while turn_params
    carried 2500, so "Right 90" and the turn she made while searching were
    different turns. Tuning one and expecting the other to improve would
    have been an afternoon lost to a discrepancy nobody could see.
    turn_params[] is now the only definition, non-const, defined once in
    mouse.cpp. The menu 90s read it, the search reads it, and ARC in the
    tuner WRITES it - so what you tune is what she runs. A tuner editing a
    local copy can only tell you what a turn would have been like; you then
    transcribed the numbers by hand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
    [app_main.cpp, config_store.cpp, mouse_config.h]
2026-09-13 Turn table: slots for the diagonal set (0.15)
    Sixteen turn types now, from four. NOTHING DRIVES ANYTHING PAST SS90R -
    the solver is four-connected, Heading has four values, and the flood
    only walks N/E/S/W, so there is no diagonal navigation to call these
    from. They are slots with correct angles and reasoned geometry waiting
    for the path generator in Ch9 and an expanded heading set. Their
    presence is not a feature.
    45 and 135 each appear TWICE on purpose. A 45 is not one turn: SD45 goes
    straight ONTO the diagonal, starting on a cell centreline and ending on
    a diagonal; DS45 does the reverse. Same angle, mirrored geometry,
    different entry and exit offsets. One row serving both is how a mouse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
    [app_main.cpp, config_store.cpp, mouse.h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]
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2026-09-13 Spins get the same treatment as the arcs (0.16)
    I fixed this for arcs an hour ago and left the identical bug sitting in
    the spins. The tuner's SPIN command edited a local copy, so a spin tuned
    at the bench changed nothing about the spin she makes at a dead end -
    and act_spin180 hardcoded omega 180 / alpha 1000 while turn_IP180 used
    360 / 3600, so "Spin 180" from the menu and the 180 she makes while
    searching were different spins. Exactly the divergence the arcs had.
    OMEGA_SPIN_TURN and ALPHA_SPIN_TURN are now runtime, defined once in
    mouse.cpp, written by the tuner, persisted as config v5. The spin ANGLE
    stays local to the tuner: it is what you are asking for on this run, not
    a property of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
    [app_main.cpp, config_store.cpp, mouse_config.h]
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2026-09-13 Connecting should greet her, not drive her (0.18)
    James's sequence explains both halves of what he saw, and the cause is
    one mistake of mine underneath them.
    The app fired the Firmware ver MENU ACTION automatically on connect.
    That action holds the OLED and waits for a button press - correct for a
    person reading a version off the display, quite wrong as an automatic
    greeting. And the screen it draws is near enough identical to the boot
    splash (version, date, time) that it read as a hang during boot rather
    than as a screen waiting for input.
    Then the button press released it and 0.13's menu_locate did exactly
    what it was built to do: pointed the menu at the action that had just
    run. Which i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
    [app_main.cpp]
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2026-09-13 Correct what SS180 is for: hairpins, not dead ends
    Ch10 and the turn-table comments both claimed SS180 would replace the
    stop-spin-go of turn_back() at a dead end. It cannot. The arc sweeps a
    full 180 mm of lateral travel - one cell pitch - so it needs the
    neighbouring column open, and a dead end is walled on both sides and
    ahead. There is nowhere to swing.
    What SS180 is actually for is the hairpin: two corridors either side of a
    dividing wall, joined at the far end, run as one continuous sweep instead
    of a 90 / straight / 90. That also makes it a speed-run turn rather than
    a search turn, because committing to the arc means knowing the neighbour
    is open before entering it, and a search only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
    [mouse_config.h]
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2026-09-14 Docs: Ch11, the sensor carrier - and the detector was the loose one
    Plotted to scale from E4-blackpill-v2.brd, the side beam does not land
    where Ch3 says it should. IR-SIDELEFT is routed at 60 deg but sits 24.8 mm
    inboard of the rim, so it is 70 mm from the wall, the shot runs 81 mm, and
    it arrives at y=129.5 - on the forward post, 1.5 mm from its trailing edge.
    That is a reading taken at the seam between this cell's wall and the next
    one's, so where the next cell has an opening the beam goes through the gap
    and the channel reports no wall while there is one beside her.
    Solving position and angle together says the angle was never the problem:
    the best azimuth is 63.6 deg against the 60 the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
    [E4_sensor_carrier_v3.stl]
2026-09-15 Sensor carrier: keep the housings, replace the carrier with a socket plate
    The V-trough carrier is abandoned. Its reasoning was sound - a 0.4 mm nozzle
    cannot hold a 5.8 mm bore to optical tolerance, while a V locates a cylinder
    whatever the print came out at - but the part kept failing on things a
    solid-model check does not look at, and every one was caught by eye in a
    slicer preview rather than by the verification:
    - every optic was blind: the trough cut started at the dome tip but the block
    face stood 0.5 mm in front of it, so all eight beams fired into PLA
    - no lead holes: all sixteen pads were covered, nothing could reach the board
    - the axis was clear but the CONE was not - 14 of 32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
    [E4_sensor_carrier_v3.stl, E4_socket_plate.stl]
2026-09-15 Sensor plate rev D: foot on the motor-mount rail
    The printed rev A gripped the board's side edges at y=58. Those grippers
    sat about 8 mm inside the wheel wells and caught the tyres: the board is
    not a rectangle plus a nose, it steps in to x 11.46/65.54 between y 14.5
    and 54.5. The plate had been checked against the parsed outline; the feet
    had been placed against a remembered one.
    Rev D drops the grippers and bolts to the motor mounts instead. Each
    mount is a 40 x 6 x 15 mm block standing on one M2 nut per stud, so the
    foot simply replaces that nut: 6 x 40 x 1.6 mm inside the silkscreen
    rail (x 14-20 and 57-63, y 14.5-54.5), both studs through it, mount
    slots back on top. Five fixings now,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
    [E4_socket_plate.stl, Motor Mounter - Color.stl, Motor Mounter - Mounter.stl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]
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2026-09-16 Open pocket clearance to 0.50 mm for MJF
    FIT 0.30 was the FDM number. Against MJF's +/-0.3 mm it has a worst case
    of zero, which is four pockets that will not take a housing without
    filing after a three-day turnaround. 0.50 gives 0.2 at the tight end and
    0.8 at the loose end, and costs about 1.5 deg of pocket-held azimuth --
    affordable because the angle is set at glue-up, sighting the emitter on a
    phone camera and peaking the detector on a live reading. The pocket is a
    fixture, not a datum.
    Re-verified at 0.50: 0 of 264 beam rays and 0 of 16 lead paths blocked,
    0 vertices in a wheel cutout, nothing above the foot inside the mount
    rail, watertight single body, 0.0 mm2 genuine overhang.
    [E4_socket_plate.stl]
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2026-09-16 Add a time-weighted route planner, and a bench to score it
    The flood in maze.h answers "fewest cells". This answers "least time", which
    is a different graph, and it does not replace the flood -- unit cost re-run
    every cell is still the right tool for the search run, where the map is
    changing underneath you. This is for the run after that.
    Why it cannot be a flood. Gradient descent over a cost-per-cell array works
    only while cost is a property of the cell. Time is not: she accelerates, so
    four one-cell moves and one four-cell straight take very different times and
    no per-cell number can express the difference. What restores additivity is
    the turn table -- every turn runs at a constant speed,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
    [planner.cpp, planner.h, timing.h]
2026-09-16 Make the planner actually buildable for the target
    It had only ever been compiled native x86-64. Cross-compiling it exposed two
    things, one of which was a claim in my own header comment that was false.
    1. It was using ~2.3 KB of stack. Route is 1.2 KB and was returned by value,
    and the parent walk used a second Step[96] scratch array. A default
    Cortex-M stack does not have that going spare. Route is now supplied by
    the caller (give it static storage), the chain is built straight into
    route.steps and reversed in place, and MAX_STEPS is 80 rather than 96 --
    the worst real maze in the repo uses 51. Stack use is now negligible.
    2. WallReader was an abstract base class. The virtu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
    [planner.cpp, planner.h]
2026-09-16 Classic diagonal substitution, costed rather than pattern-matched
    Takes the orthogonal QUICKEST route and replaces zigzags with SD45 onto the
    diagonal, a diagonal run, DS45 back off. Worth 7.8-10.4% at the as-built
    speeds on real competition mazes, and up to 17.6% once the straights are
    quick. That is a figure to weigh a weekend of SD45 tuning against.
    It is not a blind peephole. Every candidate is costed BOTH ways with the
    same model the planner uses and substituted only if the diagonal actually
    wins, so a short zigzag correctly stays on the centreline. That also makes
    it a fair opponent for the native diagonal search rather than a straw man.
    Two things it taught us on the way.
    Matching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
    [diagonal.cpp, diagonal.h, planner.cpp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]
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2026-09-16 0.21: Plan route, streamed to both companion apps
    Plan route (Maze solver, or key P) runs the planner three ways over the map
    she is holding -- shortest, quickest, quickest-with-diagonals -- and streams
    each to the apps, which draw all three over the same maze. No motors, so it
    works on an injected maze, a remembered one, or one she has just explored: a
    run can be rehearsed at the bench before she drives a cell of it.
    Points go out in HALF-CELLS, which is the unit the lattice already works in.
    Cell centres land on odd coordinates and wall midpoints on mixed ones, so a
    diagonal arrives at the app as an ordinary pair of points and neither
    companion needs to know about the lattice, the parity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
    [app_main.cpp, native.cpp]
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2026-09-16 Assert Heading and plan::Head agree instead of casting between them
    maze.h's Heading and plan::Head are separate enums that happen to list
    their compass points in the same order. act_plan_route was passing NORTH
    where plan_native wanted a Head, which is a build error in C++ -- and the
    fix that suggests itself, a cast, would have compiled happily and stayed
    correct only for as long as nobody reordered either enum.
    So the call sites now say plan::NN, and four static_asserts pin the two
    enums together. If either is ever reordered the build stops, rather than
    the mouse planning from the wrong start heading with every wall check 90
    degrees out -- a failure that would look like a maze-solver bug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
    [app_main.cpp]
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2026-09-16 0.22: fast-run speeds, separate from the search speeds
    act_plan_route built its Robot from SEARCH_SPEED and SEARCH_ACCELERATION,
    so it was planning the FAST RUN at SEARCH speed. That is why SHORTEST and
    QUICKEST came back at 34.822 s each with identical point lists: told that
    a straight is no quicker than a corner, the planner has nothing to choose
    between, and "quickest" is not a question.
    The two are not the same number and should never have shared one. Search
    speed is bounded by sensing -- she reads walls and decides where to go
    once per cell -- and is settled at the bench. The fast run has no such
    limit because the map is already known.
    RUN_SPEED 600 mm/s twice the search sp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
    [app_main.cpp, config_store.cpp, mouse_config.h]
2026-09-16 0.23: how much of the route is still guesswork
    "Have I explored enough?" had no answer but a feeling. It has one now, and
    it is a proof rather than a percentage.
    act_plan_route already flips the wall mask, so the second plan is nearly
    free. MASK_CLOSED treats an unseen wall as a wall and gives the best route
    she can PROVE. MASK_OPEN treats it as an opening and gives the best route
    that could possibly exist. The second is a true lower bound, because the
    real maze has at least as many walls as the optimistic view of it. The gap
    between them is the most that is still out there to find, and when it
    closes her route is not probably the best, it IS the best and no further
    exploring can change it.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
    [app_main.cpp, native.cpp]
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2026-09-17 0.24: the zigzag test drives the speed-run turn, and the arithmetic was wrong
    A chainable 90 is a quarter circle of radius 90 mm -- half a cell, wall
    midpoint to wall midpoint, 90 forward and 90 sideways. That is not a
    tuning choice, it is what the cell pitch is, and it is the only turn that
    composes: begin and end on a boundary, on the centreline, and the next arc
    starts exactly where the last finished.
    Her tuned turn does not. R = v/omega = 101 mm is the number everyone
    quotes, including this repository's own docs, and it is not the
    displacement -- alpha is finite, so omega ramps up and back down at both
    ends. Integrating the actual trapezoidal profile at v 300, omega 170,
    alpha 2500 give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
    [app_main.cpp]
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2026-09-17 The wall follower is its own event, not a weaker solver
    0.25's comments had this wrong in a way worth correcting rather than
    leaving. They said a wall follower "usually FAILS on a competition maze"
    and that circling the outside for ever "is what the maze is for" -- as if
    the follower were a doomed curiosity kept around for diagnostics.
    It is a separate competition class. A wall-follower course is built with a
    wall connected all the way to the centre, so a follower always arrives:
    that is the point of the event. A maze-solver maze is built the other way
    round, with the inside deliberately disconnected from the outside, so a
    follower can never reach the middle of one however long it walks.
    S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
    [app_main.cpp, mouse.h, mouse_config.h]
2026-09-17 0.26: the simulator runs at the speed the model predicts
    sim_step animated eight frames of thirty milliseconds whatever the move,
    so a cell crossing, a 90 and a dead-end reversal all took 240 ms and the
    sim told you nothing about time. It takes a DURATION now, and the frames
    follow from it: a move that costs twice as much takes twice as long to
    watch, because it does.
    The duration comes from timing.h -- the planner's own model, not a second
    one written for the animation, so the sim and the planner can never drift
    apart into two different opinions about the same mouse.
    AHEAD one cell at search speed
    90 an ARC: she rotates WHILE she travels, so it is whichever of
    the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
    [app_main.cpp, mouse.h, mouse_config.h]
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2026-09-17 0.27: the followers arm like everything else, and say so
    Two bugs, both mine, both from 0.25.
    follow_to() DID NOT WAIT. Every other action that turns a wheel calls
    sensors.wait_for_user_start() before it moves; the driven wall follower went
    straight from the button in the app to driving, with nobody necessarily near
    her. That is the more serious of the two and it is fixed at the source: she
    arms, exactly as Search and Explore do, and so does the simulated twin --
    both halves of the pair behave the same way, so neither teaches a habit the
    other punishes.
    The four followers were also missing from waitsForButtonPress, which is why
    pressing one in the app looked like nothing happening at all.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
    [mouse.h]
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2026-09-17 0.29: the executor left a diagonal by the wrong side
    James ran a diagonal speed run and she finished at (1,0) -- near the
    start, nowhere near the goal -- having walked a staircase west and south
    with no 45 degree heading in it anywhere, on a route whose time came back
    exactly right at 23199 ms.
    One line. run_route left a diagonal with
    nh = (move == MV_DS45_L) ? ((dd + 3) & 3) : ((dd + 1) & 3);
    "+3 to turn left" is correct INSIDE an enum. This crosses from Diag to
    Head, and those are different enums offset by half a turn: leaving a
    diagonal to the left is +0 and to the right is +1. The right hand was
    accidentally correct, which is why it took a real route to expose.
    What it does is wo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
    [mouse.h, native.cpp]
2026-09-17 0.30: she speeds up through ground she has already covered
    James watched a simulated explore and noticed she never speeds up in
    cells she has already been through. She does not -- sim_move_seconds()
    used FULL_CELL / SEARCH_SPEED for every cell, and search_to() crawls at
    SEARCH_SPEED from the first cell to the last. The simulator was faithfully
    showing what the firmware does, which is the simulator doing its job.
    THE TEST IS PER CELL, NOT PER LEG, and that is James's correction to my
    first framing. I proposed running the whole return leg fast because it is
    ground she has just driven. He pointed out that the flood picks the best
    KNOWN path home and known does not mean visited: she will have s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
    [mouse.h]
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2026-09-18 0.31: no toy maze at boot, and the editor can undo
    TWO THINGS LEFT OVER, both small, both worth clearing before a bench day.
    THE BOOT SCAFFOLD IS GONE. app_main seeded a two-cell bring-up maze into
    the virtual sensor on every power-up and moved the goal to (1,1) to match
    it. That was right when there were no sensor housings and no way to inject
    a real maze. It outlived that by months and became a trap: it ran on EVERY
    boot, so any goal that had been set was silently replaced, and a Plan route
    or a Sim explore against it SUCCEEDED -- against the wrong maze, with the
    wrong goal, reporting a healthy-looking two-cell solution. That is what
    cost the first Plan route run. A failure that looks lik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
    [app_main.cpp]
2026-09-18 0.32: she can finish by turning into the goal
    Every goal test in plan_native sat INSIDE the loop that advances a cell
    before it looks. So a route that ARRIVED at the goal by turning into it
    was not recognised as finished: it had to drive at least one more cell
    before the planner would call it done. On a route ending in a DS45 that is
    a whole cell given away after the clock has already stopped.
    Found by drawing Boston's centre. The route's last move was a DS45 landing
    in (8,8) -- a goal cell, clock stopped -- and it then drove south to (8,7)
    to declare GOAL.
    Two halves to the fix. plan_native now tests the node's OWN cell before
    the loop, costing nothing more because the turn that brought h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
    [diagonal.cpp, native.cpp]
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2026-09-18 0.34: the post loop, from an old lab note
    James found notes on an experiment that drove into a cell and then round a
    post continuously, watching the centre drift and adjusting alpha. It is a
    better rig than the zigzag, and the geometry says why.
    FOUR CHAINED SAME-HAND 90s OF RADIUS 90 ARE A CIRCLE CENTRED ON A POST. She
    comes up the lane at x = 90 turning right; the arc centre sits 90 mm to her
    right, at the post. After the quarter she is heading east and her right is
    now south -- the same point. Every quarter shares a centre, so the four are
    one circle, 565.5 mm round.
    Which pins omega. R = v/omega, so R = 90 at 300 mm/s needs 191 deg/s -- the
    figure SS180 already holds, because its later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
    [app_main.cpp]
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

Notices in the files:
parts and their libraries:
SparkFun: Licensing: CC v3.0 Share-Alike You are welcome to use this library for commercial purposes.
